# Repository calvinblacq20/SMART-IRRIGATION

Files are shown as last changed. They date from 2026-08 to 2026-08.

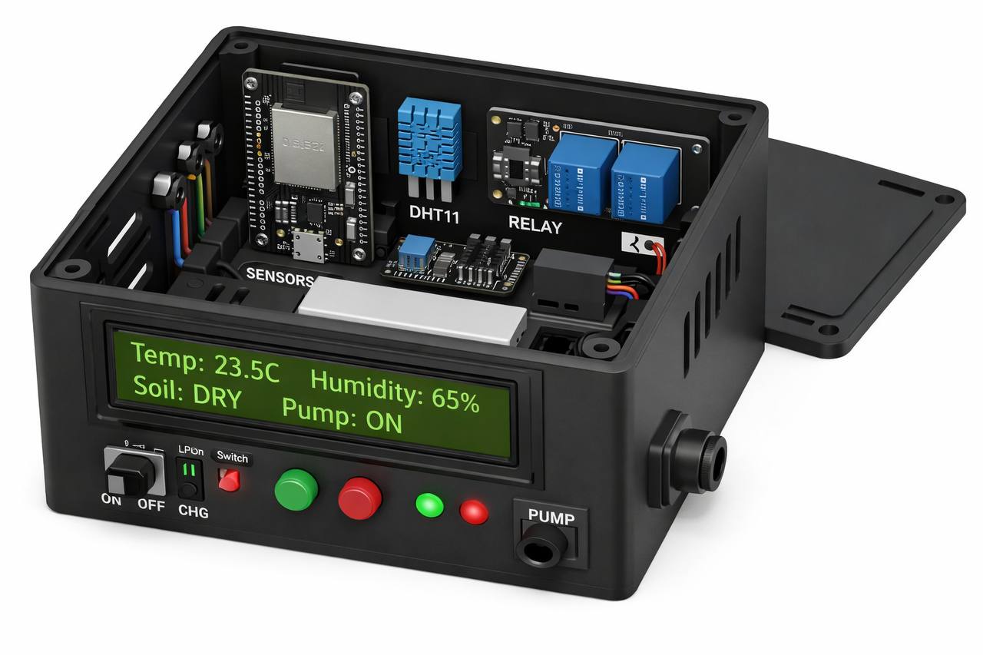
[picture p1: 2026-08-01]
photo_2_2026-06-11_17-50-46.jpg

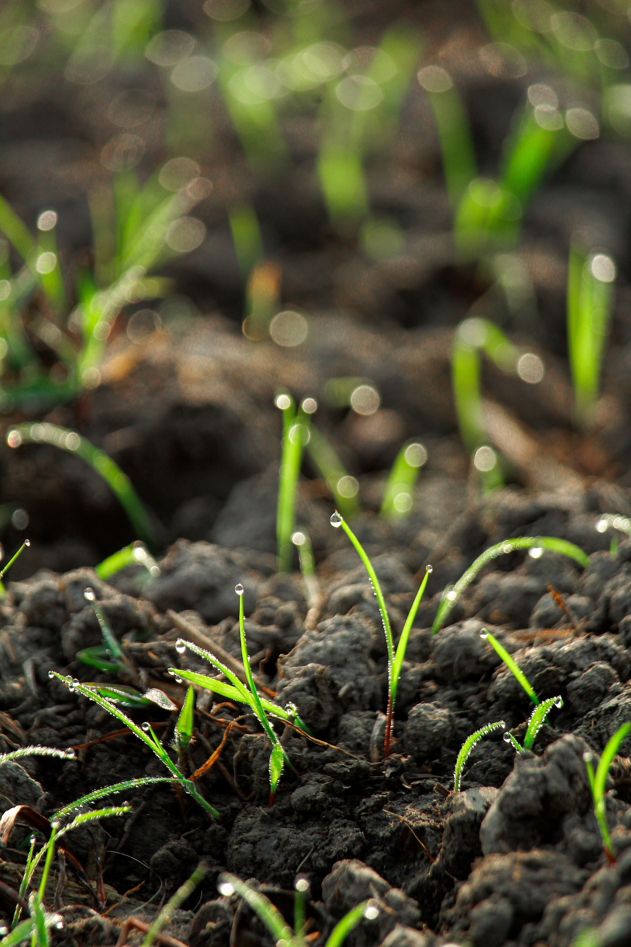
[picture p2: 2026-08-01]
webapp/bg.jpg

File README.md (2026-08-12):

# Smart Irrigation System — Project 29

An ESP8266-based automatic plant-watering controller with a REST/JSON API and a web
dashboard — servable either from the board itself or from a laptop. Reads soil moisture
and air temperature/humidity, and drives a water pump through a relay using closed-loop
control.

---

## 1. What it is (PRD summary)

**Goal.** Keep soil moisture in a healthy band automatically, with a manual override and
a clear at-a-glance status from a browser dashboard, over Wi-Fi.

**Core user action.** Watch the soil/climate readings and let the system water on its own;
optionally take manual control and tune the thresholds.

**Data shape (live state).** `soilMoisture %`, `temperature °C`, `humidity %`, `pump on/off`,
`mode auto|manual`, thresholds `startThreshold/stopThreshold`, `maxRuntimeMs`, `sensorError`.

**Control logic.** AUTO: pump ON when `soil < startThreshold`, OFF when `soil > stopThreshold`
(hysteresis). Safety: max continuous run-time (force-stop, bypasses the chatter guard) +
sensor-fault handling. MANUAL: pump follows direct API/dashboard commands.

**Out of scope.** Multi-field/multi-device fleets, cloud accounts, historical database.

---

## 2. Architecture

```
Soil sensor ──┐
              ├─► ESP8266 ──► Relay ──► Pump
DHT22 ────────┘      │
                      ├─► REST/JSON API  /api/status /api/config /api/pump /api/mode
                      │        │
                      │        ├─► dashboard served from the board itself (LittleFS,
                      │        │   gradient-mesh background) — same-origin, no laptop
                      │        │
                      │        └─► webapp/index.html (video background), served from a
                      │            laptop or Vercel, calling the API over the LAN
                      └─► mDNS  smart-irrigation.local
```

- **Firmware (active — ESP8266):** `firmware/smart_irrigation_esp8266/smart_irrigation_esp8266.ino`
  — the current connection layer: sensors, hysteresis control, REST + JSON API, mDNS. The dashboard
  is wired to this. (An earlier ESP32 build with LCD/LEDs/NVS lives in `firmware/smart_irrigation/`.)
- **Simulation:** `firmware/wokwi/` — runs the whole thing in the browser at wokwi.com.
- **Web dashboard — two builds, same UI/API, different background:**
  - `webapp/index.html` — full version with the **video background**; serve it from a laptop
    (or Vercel for a demo). Canvas soil gauge, sparklines, soil-trend chart, Home/Data/Device/
    Settings views, live + demo mode, installable (manifest + offline service worker + Install
    button).
  - `firmware/smart_irrigation_esp8266/data/index.html` — the **same dashboard**, lightweight
    (animated gradient-mesh background instead of video — the video is ~4.7 MB and won't fit on
    the board's flash). This one is **served by the ESP8266 itself** at its own IP /
    `smart-irrigation.local`, so no laptop or Vercel is needed at all — open the board's address
    on any phone/browser on the Wi-Fi and the dashboard is right there, same-origin with the API.
- **Device API:** a Wi-Fi web server on the ESP8266 exposing the JSON the dashboard reads/writes.

### Web API contract (dashboard is coded to this)
| Method/Path | Purpose |
|---|---|
| `GET /api/status` | full live state as JSON (`soilMoisture, temperature, humidity, pump, mode, sensorError, …`) |
| `GET /api/config` | thresholds: `startThreshold, stopThreshold, maxRuntimeMs` |
| `POST /api/pump` | body `{ "state": true\|false }` — manual pump (forces manual mode) |
| `POST /api/mode` | body `{ "mode": "auto"\|"manual" }` |
| `POST /api/config` | body `{ startThreshold, stopThreshold, maxRuntimeMs }` — update + clamp |

All responses send `Access-Control-Allow-Origin: *` so the standalone site can call the board.
mDNS is enabled — the board is reachable at `http://smart-irrigation.local`.

---

## 3. Repository map

| Path | What |
|---|---|
| `firmware/smart_irrigation_esp8266/` | **active firmware** — ESP8266, DHT22, REST/JSON API + mDNS |
| `firmware/smart_irrigation_esp8266/data/` | dashboard **served by the board** via LittleFS (lightweight, no video) — upload separately from the sketch, see §4 |
| `firmware/smart_irrigation/` | earlier ESP32 build (DHT11, LCD, LEDs, NVS) |
| `firmware/wokwi/` | Wokwi sim: `diagram.json`, `sketch.ino`, `libraries.txt` |
| `firmware/wiring_diagram.png` | connection diagram |
| `webapp/` | Dashboard — single-file `index.html` (**full, video background**) + `sw.js`, `manifest.json` (installable/offline). `package.json`/`vite.config.js` are just for the dev server |
| `webapp/bg.mp4`, `bg.jpg` | dashboard background video + poster |
| `*.stl` / `*.step` | 3D enclosure (body + lid), 150×120×60 mm |
| `Project29_*_Report.docx` | enclosure + firmware/software reports |

---

## 4. How to run each piece

- **Flash the board:** open `firmware/smart_irrigation_esp8266/smart_irrigation_esp8266.ino`
  in Arduino IDE, board = *NodeMCU 1.0 (ESP-12E)*, Flash Size = *4MB (FS:2MB OTA:~1019KB)*
  (the default on most boards), install **DHT sensor library** + **Adafruit Unified Sensor** +
  **ArduinoJson** + **LiquidCrystal I2C** (Frank de Brabander), fill in your Wi-Fi SSID/password,
  upload. The Serial monitor prints the IP and the dashboard URL.
  **v2.0.0 pin map:** soil → A0, DHT22 → **D7** (GPIO13 — D2 is now the I2C bus), relay → D6,
  20x4 I2C LCD (addr `0x27`) → D2 (SDA) / D1 (SCL), Manual button → D5 (to GND), Auto button →
  **D3/GPIO0** (to GND — don't hold it while powering on/resetting, it's the boot-mode pin).
  Settings persist across reboots (EEPROM).
- **Upload the on-board dashboard (LittleFS) — do this once, separately from the sketch upload:**
  install the LittleFS uploader tool — IDE 2.x: the *arduino-littlefs-upload* plugin
  ([releases](https://github.com/earlephilhower/arduino-littlefs-upload/releases), drop the
  `.vsix` in `%USERPROFILE%\.arduinoIDE\plugins\`, restart, then `Ctrl+Shift+P` →
  "Upload LittleFS to Pico/ESP8266/ESP32"; close the Serial Monitor first). IDE 1.x: the
  *ESP8266 LittleFS Data Upload* plugin. This packs `firmware/smart_irrigation_esp8266/data/`
  onto the board's flash — after that, opening the board's IP in any browser shows the dashboard
  directly, no laptop needed.
- **Simulate:** `firmware/wokwi/` — logic demonstration at wokwi.com.
- **Dashboard (video version, laptop/Vercel):** from `webapp/`, run `npm install` then
  `npm run dev -- --host` (or just serve the folder: `python -m http.server 8000`). Open it on a
  phone/laptop on the **same Wi-Fi** as the board, then Connect to `http://smart-irrigation.local`
  (or the board's IP). "Install" adds it to the home screen; the app shell then works offline.

---

## 5. Status & remaining work

1. **Firmware + dashboard** ✅ — ESP8266 REST firmware and both dashboard builds speak the same
   contract. Fill in your SSID/password, flash, (optionally) upload the LittleFS dashboard, connect.
2. **Enclosure** — the 3D enclosure still carries an LCD window / button holes from the earlier
   ESP32 build; the ESP8266 build has no on-device UI, so those provisions are now optional.
3. **Deploy** (optional) — the video-background dashboard runs from any static host (e.g. Vercel),
   but an HTTPS host cannot call an `http://` board (mixed content) — that build is demo/showcase
   only unless the dashboard is served locally or from the board itself (see §4).

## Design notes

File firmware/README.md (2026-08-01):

# Smart Irrigation System — Firmware Package

ESP32 firmware for the Smart Irrigation System (the enclosure you already 3D-modelled).
This is the **software stage** of the project. Everything you need to flash, calibrate,
and demo is here.

---

## 1. What the system does

- Reads **soil moisture**, **temperature + humidity (DHT11)**, and **light (LDR)**.
- **AUTO mode:** turns the water pump ON when soil drops below the *Dry* threshold and
  OFF when it rises above the *Wet* threshold (hysteresis, so it doesn't chatter).
- **MANUAL mode:** the pump is toggled by the MANUAL button.
- **Safety:** the pump can never run longer than *Max run* seconds, and must wait
  *Cooldown* seconds between waterings.
- **LCD 20×4** shows a live dashboard; the 3 buttons drive a settings menu.
- **LEDs:** green = healthy/idle, red = pump running or soil dry, red **blinking** = sensor fault.
- **Settings persist** in flash (survive power-off).

---

## 2. Software you need (Arduino IDE)

1. **Boards Manager** → install **“esp32” by Espressif** (adds ESP32 Dev Module).
2. **Library Manager** → install:
   - **LiquidCrystal I2C** (Frank de Brabander)
   - **DHT sensor library** (Adafruit)
   - **Adafruit Unified Sensor** (dependency of the DHT library)
   - *Preferences* and *Wire* already ship with the ESP32 core.
3. **Tools → Board:** `ESP32 Dev Module`. **Upload speed:** 921600. Select your COM port.
4. Open `smart_irrigation/smart_irrigation.ino`, click **Upload**.

Open **Serial Monitor @ 115200** to watch live readings.

---

## 3. Wiring (matches the circuit diagram)

> These are the pins the firmware uses. If any wire on your board goes to a different
> GPIO, just change that one `#define` at the top of the `.ino` — nothing else.

| Component | Signal | ESP32 pin |
|---|---|---|
| DHT11 | DATA | GPIO4 |
| Soil moisture | A0 (analog) | GPIO34 (ADC, input-only) |
| LDR module | OUT (analog) | GPIO35 (ADC, input-only) |
| LCD 20×4 (I2C) | SDA | GPIO18 |
| LCD 20×4 (I2C) | SCL | GPIO19 |
| Relay ch1 | IN1 → pump | GPIO22 |
| Relay ch2 | IN2 → spare/valve | GPIO23 |
| Button MANUAL | signal | GPIO25 |
| Button MENU | signal | GPIO26 |
| Button SETTINGS | signal | GPIO27 |
| Green LED (+220 Ω) | anode | GPIO17 |
| Red LED (+220 Ω) | anode | GPIO16 |

Power/common:
- Sensor **VCC → 3V3**, all **GND → GND** (common ground with the relay and LEDs).
- Buttons: one leg to the GPIO, the other leg to **GND** (firmware uses internal pull-ups,
  so no external resistors needed — pressed = LOW).
- **Relay board VCC → 5V (VIN)** if you have it; the coils are happier at 5V.
- **Pump is powered from the battery through the relay contacts, NOT from the ESP32.**
  Wire: Battery+ → relay **COM1**, relay **NO1** → pump+, pump− → Battery−. Add a
  flyback diode across a DC pump if the module doesn't already isolate it.

### Pins you should double-check against your own diagram
Everything works regardless, but these are the 2 worth a 5-second look:
- **I2C (LCD)** — I read your diagram’s `D18 (SDA) / D19 (SCL)` labels. If you actually
  wired the LCD to the ESP32’s default `GPIO21/GPIO22`, change `PIN_SDA`/`PIN_SCL` to `21`/`22`.
- **Relay active level** — most blue 2-channel boards are **active-LOW** (default here).
  If your pump turns on when it should be off, set `#define RELAY_ACTIVE_LOW 0`.

---

## 4. Calibrating the soil sensor (do this once)

ESP32 analog readings are 0–4095. You must tell the firmware what "dry" and "wet" look like:

1. Upload the firmware, open Serial Monitor. Each line prints `soil=..%(rawNNNN)`.
2. Hold the probe **in dry air** → note the `raw` number → put it in `SOIL_RAW_DRY`.
3. Dip the probe **in a glass of water** (up to the line) → note `raw` → put it in `SOIL_RAW_WET`.
4. Re-upload. Now `Soil:` shows ~0 % dry and ~100 % wet.

(Optional) Do the same for the LDR with `LDR_RAW_DARK` / `LDR_RAW_BRIGHT`.

---

## 5. Using the buttons

**Home screen**
- **MANUAL** — toggles the pump on/off (switches the system into MANUAL mode).
- **MENU** or **SETTINGS** — opens the settings list.

**Settings list**
- **MENU** — move to the next item.
- **SETTINGS** — edit the highlighted item (or run *Save & Exit*).
- **MANUAL** — back to Home without saving.

**Edit screen**
- **SETTINGS (+)** / **MENU (−)** — change the value.
- **MANUAL** — confirm, back to the list.

Adjustable settings: **Mode** (AUTO/MANUAL), **Dry threshold %**, **Wet threshold %**,
**Max run (s)**, **Cooldown (s)**, **Night-only** (water only when dark). Choose
*Save & Exit* to store them permanently.

---

## 6. Test / verification checklist (for your demo & report)

| # | Test | Expected result |
|---|---|---|
| 1 | Power on | LCD splash → dashboard; green LED on |
| 2 | Squeeze probe / put in water | Soil % rises; in AUTO the pump stays OFF above Wet% |
| 3 | Probe in dry air (AUTO) | Below Dry%, pump turns ON, red LED on |
| 4 | Keep pump running | After *Max run* s it auto-stops (safety) |
| 5 | Press MANUAL | Pump toggles on/off immediately |
| 6 | Unplug soil sensor | Red LED blinks (fault), pump forced OFF |
| 7 | Cover the LDR with Night-only = YES | Watering allowed only while dark |
| 8 | Change a setting → Save & Exit → reboot | New value is remembered |
| 9 | Breadboard vs enclosure | Same behaviour after transplant |

---

## 7. Troubleshooting

| Symptom | Fix |
|---|---|
| LCD blank / boxes only | Try `LCD_ADDR 0x3F`; check SDA/SCL not swapped; tweak the LCD contrast pot |
| Pump logic inverted | Set `RELAY_ACTIVE_LOW 0` |
| Soil always 0 % or 100 % | Re-run calibration (step 4); confirm A0 → GPIO34 |
| Temp/Hum show `--` | DHT11 needs VCC on 3V3, ~1 s warm-up; check DATA → GPIO4 |
| Pump won’t stop / ESP resets when pump runs | Power the pump from the battery via the relay, never from the ESP32; add flyback diode |
| WiFi later? | Move analog sensors to ADC1 pins only (GPIO32–39) — already done here |

---

## 8. Where this fits in the project

1. ✅ Circuit (line) diagram
2. ✅ 3D enclosure model  (`../body.stl`, `../lid.stl` — now correctly 150×120×60 mm)
3. ✅ Breadboard layout
4. ✅ Hand sketch
5. **➡ Firmware (this package)**
6. Assembly & wiring inside the enclosure
7. Calibration + testing (use the checklist above)
8. Final report (circuit + code + test results + photos)

Firmware file: `smart_irrigation/smart_irrigation.ino`

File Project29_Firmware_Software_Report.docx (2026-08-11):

PROJECT 29 — SMART IRRIGATION SYSTEM

Firmware / Software Report

Name | Index No. | Course | Platform
Calvin | 8985323 | Embedded Systems | ESP8266 (Arduino)

1. Software Overview

This report documents the control firmware for the Project 29 Smart Irrigation System. The firmware runs on an ESP8266 Wi-Fi module (NodeMCU) and turns the sensor and actuator hardware into a self-contained, automatic plant-watering controller with a manual override. It reads soil moisture and air temperature/humidity (DHT22), decides when the plant needs water, and switches a DC pump through a relay. Instead of an on-device LCD, the controller exposes a small REST/JSON API over Wi-Fi and advertises itself over mDNS as smart-irrigation.local; a companion installable web app (PWA) is the user interface, giving live telemetry and control from any phone or laptop on the same network.

2. Operating Principle

The controller supports two modes:

- AUTO mode uses closed-loop control with hysteresis. The pump switches ON when the soil moisture falls below the Start threshold and switches OFF once it rises above the Stop threshold. The gap between the two thresholds prevents the pump from rapidly cycling around a single set-point.
- MANUAL mode lets the operator switch the pump directly from the web app; issuing a manual pump command automatically places the controller in MANUAL mode.

Three protection rules apply: a maximum continuous run-time force-stops the pump after a set time; a 5-second chatter guard prevents relay oscillation on rapid toggles (safety shut-offs bypass this guard so they can never be swallowed); and a DHT read-failure or an apparently disconnected soil probe is flagged as a sensor fault, pausing automatic watering.

3. Hardware / Software Interface (Pin Map)

The firmware addresses each component through the ESP8266 (NodeMCU) pins below. The soil probe uses the single analog input A0; the DHT22 and relay use digital GPIOs.

Component | Signal | NodeMCU Pin | GPIO
Soil moisture sensor | AOUT (analog) | A0 | ADC0
DHT22 | DATA | D2 | GPIO4
Relay module | IN -> pump | D6 | GPIO12

The relay is active-HIGH in this build (RELAY_ON = HIGH). The relay output is initialised to OFF before the pin is set to OUTPUT, preventing a pump blip at boot. The pump is driven from its own supply through the relay contacts, never from a GPIO; fit a flyback diode across an inductive pump.

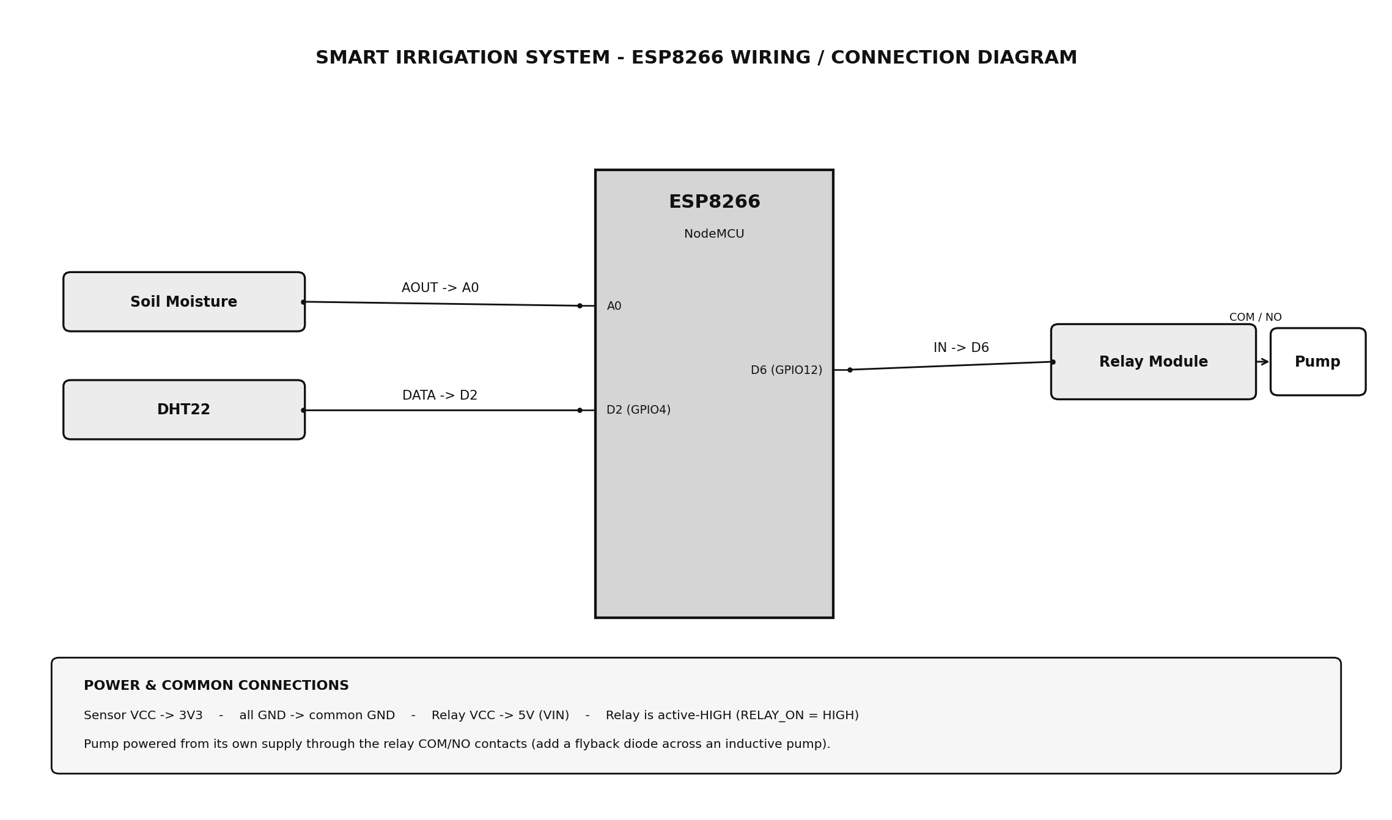
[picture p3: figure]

Figure 1 - ESP8266 wiring / connection diagram. Signal wires are labelled with the pin; power and common connections are summarised in the lower panel.

4. Program Structure & Control Flow

The program is fully non-blocking: setup() initialises the peripherals and connects to Wi-Fi, then loop() services the web server, mDNS, Wi-Fi health, the sensors, the safety timer and the control logic on their own timers without ever calling a long delay. This keeps the REST API responsive while the sensors and pump logic run in the background.

Function | Responsibility
readSensors | Timed DHT22 + soil reads; map raw ADC to 0-100 %, keep last good DHT value
updateIrrigation | AUTO hysteresis + soil-disconnect safety (skipped in MANUAL)
handlePumpSafety | Force-stop the pump once max run-time is exceeded
setPump | Drive the relay with a 5 s chatter guard (safety shut-offs force through)
handleWiFi | Non-blocking reconnect if the link drops
/api/status, /api/config | Serve live telemetry and thresholds as JSON
/api/pump, /api/mode, /api/config (POST) | Apply control + clamp settings

5. Build Environment & Libraries

Item | Selection
IDE | Arduino IDE
Board package | esp8266 by ESP8266 Community
Board | NodeMCU 1.0 (ESP-12E Module)
Upload speed | 115200 baud
Serial monitor | 115200 baud
Library | DHT sensor library (Adafruit)
Library | Adafruit Unified Sensor
Library | ArduinoJson (v6)
Built-in | ESP8266WiFi, ESP8266WebServer, ESP8266mDNS (core)

6. Soil-Sensor Calibration

Because raw ADC values depend on the specific probe and soil, the sensor is calibrated once and the two reference values are stored in the firmware constants SOIL_DRY_RAW and SOIL_WET_RAW:

- Open the Serial Monitor at 115200 baud.
- Hold the probe in dry air and record the raw value into SOIL_DRY_RAW.
- Dip the probe in a glass of water and record the raw value into SOIL_WET_RAW.
- Re-upload; the moisture reading then shows ~0 % dry and ~100 % wet.

7. REST API & Web App (User Interface)

The user interface is a Progressive Web App served separately (webapp/). It polls the controller every 3 seconds and issues control commands over the following endpoints; every response carries CORS headers so the app may be served from any local origin.

Method / Path | Purpose
GET /api/status | Live JSON: soilMoisture, temperature, humidity, pump, mode, sensorError, ip, uptime
GET /api/config | Thresholds: startThreshold, stopThreshold, maxRuntimeMs
POST /api/pump | Body {"state": true|false} - manual pump (also forces MANUAL mode)
POST /api/mode | Body {"mode": "auto"|"manual"}
POST /api/config | Body {startThreshold, stopThreshold, maxRuntimeMs} - update + clamp

On the config write the firmware clamps both thresholds to 0-100 %, clamps the run-time to 3 s - 10 min, and enforces start < stop, so an out-of-range request can never leave the controller in an unsafe state.

8. Testing & Results

The firmware was verified against the following functional tests. Record the observed result in the last column during your demonstration.

# | Test | Expected result | Pass

1 | Power on | Serial prints IP; app connects at smart-irrigation.local
2 | Probe in water (AUTO) | Soil % high; pump stays OFF above Stop %
3 | Probe in dry air (AUTO) | Below Start %, pump turns ON
4 | Hold pump running | Force-stops after Max run-time (safety)
5 | Toggle pump in app | Pump switches; controller flips to MANUAL
6 | Unplug DHT / soil probe | sensorError = true; auto watering paused
7 | POST out-of-range config | Values clamped; start < stop preserved
8 | Drop Wi-Fi, restore | Controller reconnects; app resumes polling

9. Complete Source Code Listing

File: smart_irrigation_esp8266/smart_irrigation_esp8266.ino

/*==============================================================================

SMART IRRIGATION SYSTEM — ESP8266 firmware (NodeMCU / Wemos D1)

Project 29 — updated connection layer.

REST API (dashboard is wired to this exact contract):

GET /api/status -> full live state JSON

GET /api/config -> { startThreshold, stopThreshold, maxRuntimeMs }

POST /api/pump body { "state": true|false } (forces manual mode)

POST /api/mode body { "mode": "auto"|"manual" }

POST /api/config body { startThreshold, stopThreshold, maxRuntimeMs }

OPTIONS * -> CORS pre-flight

Board: ESP8266. Sensors: soil (A0), DHT22 (D2/GPIO4). Relay: D6/GPIO12.

mDNS: http://smart-irrigation.local

Libraries (Library Manager): DHT sensor library (Adafruit), ArduinoJson (v6).

ESP8266WiFi / ESP8266WebServer / ESP8266mDNS ship with the ESP8266 core.

==============================================================================*/

#include <ESP8266WiFi.h>

#include <ESP8266WebServer.h>

#include <ESP8266mDNS.h>

#include <DHT.h>

#include <ArduinoJson.h>

#define FIRMWARE_VERSION "1.0.0"

// ==========================================

// CONFIGURATION (Adjust these before flashing)

// ==========================================

const char* WIFI_SSID = "YOUR_WIFI_NAME";

const char* WIFI_PASSWORD = "YOUR_WIFI_PASSWORD";

// Hardware Pins

const int PIN_SOIL_SENSOR = A0;

const int PIN_DHT = 4; // D2

const int PIN_RELAY = 12; // D6

// Relay logic (Change to LOW if using an Active-Low relay module)

const int RELAY_ON = HIGH;

const int RELAY_OFF = LOW;

// Soil Moisture Calibration (Raw ADC values 0-1023)

const int SOIL_DRY_RAW = 800; // Value when probe is completely dry in air

const int SOIL_WET_RAW = 300; // Value when probe is submerged in water

// DHT Setup

#define DHTTYPE DHT22

DHT dht(PIN_DHT, DHTTYPE);

// Web Server

ESP8266WebServer server(80);

// ==========================================

// SYSTEM STATE

// ==========================================

float currentTemp = 0.0;

float currentHum = 0.0;

int currentMoisture = 0; // Percentage 0-100

bool isPumpOn = false;

bool isAutoMode = true;

bool dhtError = false;

// Configurable Settings

int configStartThreshold = 35; // Start watering below 35%

int configStopThreshold = 45; // Stop watering above 45%

unsigned long configMaxPumpRuntime = 30000; // 30 seconds

// Safety clamps for /api/config

const unsigned long RUNTIME_MIN = 3000UL; // 3 s (never below the chatter window)

const unsigned long RUNTIME_MAX = 600000UL; // 10 min

// Timers & Safety

unsigned long lastDHTReadTime = 0;

unsigned long lastSoilReadTime = 0;

unsigned long lastWiFiCheckTime = 0;

unsigned long pumpStartTime = 0;

unsigned long lastRelaySwitchTime = 0;

const unsigned long DHT_INTERVAL = 2500; // 2.5 seconds

const unsigned long SOIL_INTERVAL = 1000; // 1 second

const unsigned long WIFI_INTERVAL = 10000; // 10 seconds

const unsigned long MIN_RELAY_DELAY = 5000;// Minimum 5 seconds between relay toggles (Chatter protection)

// ==========================================

// SETUP

// ==========================================

void setup() {

Serial.begin(115200);

delay(100);

Serial.println(F("\n===================================="));

Serial.println(F("SMART IRRIGATION SYSTEM"));

Serial.print(F("Firmware: "));

Serial.println(FIRMWARE_VERSION);

Serial.print(F("Reset Reason: "));

Serial.println(ESP.getResetReason());

Serial.println(F("===================================="));

initializePins();

initializeSensors();

initializeWiFi();

initializeWebServer();

initializeMDNS();

Serial.println(F("System ready."));

}

// ==========================================

// LOOP

// ==========================================

void loop() {

server.handleClient();

MDNS.update();

handleWiFi();

readSensors();

handlePumpSafety();

updateIrrigation();

}

// ==========================================

// INITIALIZATION FUNCTIONS

// ==========================================

void initializePins() {

// IMPORTANT: Set default state BEFORE making it an output to prevent relay blips on boot

digitalWrite(PIN_RELAY, RELAY_OFF);

pinMode(PIN_RELAY, OUTPUT);

Serial.println(F("Pins initialized. Pump is OFF."));

}

void initializeSensors() {

dht.begin();

Serial.println(F("Sensors initialized."));

}

void initializeWiFi() {

Serial.print(F("Connecting to WiFi: "));

Serial.println(WIFI_SSID);

WiFi.mode(WIFI_STA);

WiFi.begin(WIFI_SSID, WIFI_PASSWORD);

// Non-blocking wait, give it 10 seconds maximum during boot

unsigned long startAttemptTime = millis();

while (WiFi.status() != WL_CONNECTED && millis() - startAttemptTime < 10000) {

delay(500);

Serial.print(F("."));

}

if (WiFi.status() == WL_CONNECTED) {

Serial.println(F("\nWiFi connected."));

Serial.print(F("IP address: "));

Serial.println(WiFi.localIP());

} else {

Serial.println(F("\nWiFi connection timed out. Proceeding offline."));

}

}

void initializeMDNS() {

if (MDNS.begin("smart-irrigation")) {

MDNS.addService("http", "tcp", 80);

Serial.println(F("mDNS responder started at smart-irrigation.local"));

}

}

// ==========================================

// CORE LOGIC FUNCTIONS

// ==========================================

void handleWiFi() {

if (millis() - lastWiFiCheckTime >= WIFI_INTERVAL) {

lastWiFiCheckTime = millis();

if (WiFi.status() != WL_CONNECTED) {

Serial.println(F("WiFi disconnected. Attempting reconnect (non-blocking)..."));

WiFi.disconnect();

WiFi.begin(WIFI_SSID, WIFI_PASSWORD);

}

}

}

void readSensors() {

unsigned long currentMillis = millis();

// Read DHT22

if (currentMillis - lastDHTReadTime >= DHT_INTERVAL) {

lastDHTReadTime = currentMillis;

float t = dht.readTemperature();

float h = dht.readHumidity();

if (isnan(t) || isnan(h)) {

if (!dhtError) {

Serial.println(F("Warning: DHT sensor read failure."));

dhtError = true;

}

} else {

currentTemp = t;

currentHum = h;

dhtError = false;

}

}

// Read Soil Moisture

if (currentMillis - lastSoilReadTime >= SOIL_INTERVAL) {

lastSoilReadTime = currentMillis;

int rawValue = analogRead(PIN_SOIL_SENSOR);

// Map raw ADC to percentage, constrain to 0-100

currentMoisture = map(rawValue, SOIL_DRY_RAW, SOIL_WET_RAW, 0, 100);

currentMoisture = constrain(currentMoisture, 0, 100);

}

}

// force=true bypasses chatter protection — used ONLY by safety shut-offs so a

// max-runtime or sensor-fault cutoff can never be swallowed by the 5 s guard.

void setPump(bool state, String reason, bool force = false) {

if (!force && millis() - lastRelaySwitchTime < MIN_RELAY_DELAY) {

return; // Ignore normal command if trying to switch too fast

}

if (state && !isPumpOn) {

digitalWrite(PIN_RELAY, RELAY_ON);

isPumpOn = true;

pumpStartTime = millis();

lastRelaySwitchTime = millis();

Serial.print(F("Pump ON - Reason: "));

Serial.println(reason);

}

else if (!state && isPumpOn) {

digitalWrite(PIN_RELAY, RELAY_OFF);

isPumpOn = false;

lastRelaySwitchTime = millis();

Serial.print(F("Pump OFF - Reason: "));

Serial.println(reason);

}

}

void updateIrrigation() {

if (!isAutoMode) return;

// Sanity check: If moisture sensor disconnected/broken, do not water

if (currentMoisture <= 0 && analogRead(PIN_SOIL_SENSOR) > 1000 && SOIL_DRY_RAW < 1000) {

if (isPumpOn) setPump(false, "Safety: Soil sensor appears disconnected", true);

return;

}

// Hysteresis logic

if (currentMoisture < configStartThreshold && !isPumpOn) {

setPump(true, "Auto Start (Moisture Low)");

}

else if (currentMoisture > configStopThreshold && isPumpOn) {

setPump(false, "Auto Stop (Moisture High)");

}

}

void handlePumpSafety() {

if (isPumpOn) {

if (millis() - pumpStartTime >= configMaxPumpRuntime) {

setPump(false, "Safety: Max Runtime Exceeded", true); // force: must never be blocked

}

}

}

// ==========================================

// HTTP SERVER / API HANDLERS

// ==========================================

void sendCORSHeaders() {

server.sendHeader(F("Access-Control-Allow-Origin"), F("*"));

server.sendHeader(F("Access-Control-Allow-Methods"), F("GET, POST, OPTIONS"));

server.sendHeader(F("Access-Control-Allow-Headers"), F("Content-Type"));

}

void handleOptions() {

sendCORSHeaders();

server.send(204); // No Content

}

void initializeWebServer() {

// Pre-flight CORS request

server.onNotFound([]() {

if (server.method() == HTTP_OPTIONS) {

handleOptions();

} else {

sendCORSHeaders();

server.send(404, "application/json", "{\"success\":false,\"error\":\"Not Found\"}");

}

});

server.on("/api/status", HTTP_GET, []() {

StaticJsonDocument<384> doc;

doc["device"] = "smart-irrigation";

doc["version"] = FIRMWARE_VERSION;

doc["ip"] = WiFi.localIP().toString();

doc["uptime"] = millis() / 1000;

doc["wifi"] = (WiFi.status() == WL_CONNECTED);

doc["mode"] = isAutoMode ? "auto" : "manual";

doc["pump"] = isPumpOn;

doc["soilMoisture"] = currentMoisture;

doc["temperature"] = currentTemp;

doc["humidity"] = currentHum;

doc["sensorError"] = dhtError;

String response;

serializeJson(doc, response);

sendCORSHeaders();

server.send(200, "application/json", response);

});

server.on("/api/config", HTTP_GET, []() {

StaticJsonDocument<200> doc;

doc["startThreshold"] = configStartThreshold;

doc["stopThreshold"] = configStopThreshold;

doc["maxRuntimeMs"] = configMaxPumpRuntime;

String response;

serializeJson(doc, response);

sendCORSHeaders();

server.send(200, "application/json", response);

});

server.on("/api/pump", HTTP_POST, []() {

sendCORSHeaders();

if (server.hasArg("plain") == false) {

server.send(400, "application/json", "{\"success\":false,\"error\":\"Body required\"}");

return;

}

StaticJsonDocument<200> doc;

DeserializationError error = deserializeJson(doc, server.arg("plain"));

if (error) {

server.send(400, "application/json", "{\"success\":false,\"error\":\"Invalid JSON\"}");

return;

}

if (!doc.containsKey("state")) {

server.send(400, "application/json", "{\"success\":false,\"error\":\"Missing 'state' boolean\"}");

return;

}

bool requestedState = doc["state"];

// Switch to manual mode if controlling pump via API

isAutoMode = false;

setPump(requestedState, "API Manual Request");

// Report the ACTUAL pump state (chatter protection may have deferred the switch)

String resp = String("{\"success\":true,\"pump\":") + (isPumpOn ? "true" : "false") + "}";

server.send(200, "application/json", resp);

});

server.on("/api/mode", HTTP_POST, []() {

sendCORSHeaders();

if (server.hasArg("plain") == false) {

server.send(400, "application/json", "{\"success\":false,\"error\":\"Body required\"}");

return;

}

StaticJsonDocument<200> doc;

DeserializationError error = deserializeJson(doc, server.arg("plain"));

if (error) {

server.send(400, "application/json", "{\"success\":false,\"error\":\"Invalid JSON\"}");

return;

}

String mode = doc["mode"];

if (mode == "auto") {

isAutoMode = true;

} else if (mode == "manual") {

isAutoMode = false;

} else {

server.send(400, "application/json", "{\"success\":false,\"error\":\"Invalid mode\"}");

return;

}

server.send(200, "application/json", "{\"success\":true}");

});

server.on("/api/config", HTTP_POST, []() {

sendCORSHeaders();

if (server.hasArg("plain") == false) {

server.send(400, "application/json", "{\"success\":false,\"error\":\"Body required\"}");

return;

}

StaticJsonDocument<200> doc;

DeserializationError error = deserializeJson(doc, server.arg("plain"));

if (error) {

server.send(400, "application/json", "{\"success\":false,\"error\":\"Invalid JSON\"}");

return;

}

if (doc.containsKey("startThreshold")) configStartThreshold = doc["startThreshold"];

if (doc.containsKey("stopThreshold")) configStopThreshold = doc["stopThreshold"];

if (doc.containsKey("maxRuntimeMs")) configMaxPumpRuntime = doc["maxRuntimeMs"].as<unsigned long>();

// Validate boundaries (clamp to sane ranges, then enforce hysteresis gap)

configStartThreshold = constrain(configStartThreshold, 0, 100);

configStopThreshold = constrain(configStopThreshold, 0, 100);

if (configMaxPumpRuntime < RUNTIME_MIN) configMaxPumpRuntime = RUNTIME_MIN;

if (configMaxPumpRuntime > RUNTIME_MAX) configMaxPumpRuntime = RUNTIME_MAX;

if (configStartThreshold >= configStopThreshold) {

configStartThreshold = configStopThreshold - 5; // Enforce minimum hysteresis

if (configStartThreshold < 0) configStartThreshold = 0;

}

server.send(200, "application/json", "{\"success\":true}");

});

server.begin();

}

10. Conclusion

The firmware implements the full Project 29 control scheme: automatic hysteresis-based irrigation with manual override, a REST/JSON API with an installable web app for configuration and monitoring, safety limits (max run-time, chatter guard, sensor-fault handling) and input clamping. It compiles for the NodeMCU (ESP8266) using the standard Arduino toolchain and maps directly to the components in the circuit diagram, completing the software stage of the project.

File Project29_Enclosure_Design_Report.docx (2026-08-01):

PROJECT 29 — SMART IRRIGATION SYSTEM

Enclosure Design Report

Name | Index No. | Course | Date
Calvin | 8985323 | Embedded Systems | 11 June 2026

1. Design Overview

The enclosure is a benchtop instrument case that houses the complete Smart Irrigation controller. The display and all user controls sit on the front panel for easy reading and operation, while the ESP32, DHT11 and relay module mount on internal standoffs above a dedicated battery bay. A removable lid gives full access for assembly and debugging. This layout was chosen over a sealed weatherproof box because the unit is operated and graded on a desk, and every component must remain visible and serviceable.

2. Overall Dimensions

All dimensions are stated in centimetres (cm), as required.

Parameter | Value (cm)
Overall width | 15.0
Overall depth | 12.0
Overall height | 6.0
Wall thickness | 0.3
Corner radius | 0.6
Lid clearance | 0.04

3. Dimensioned Drawing

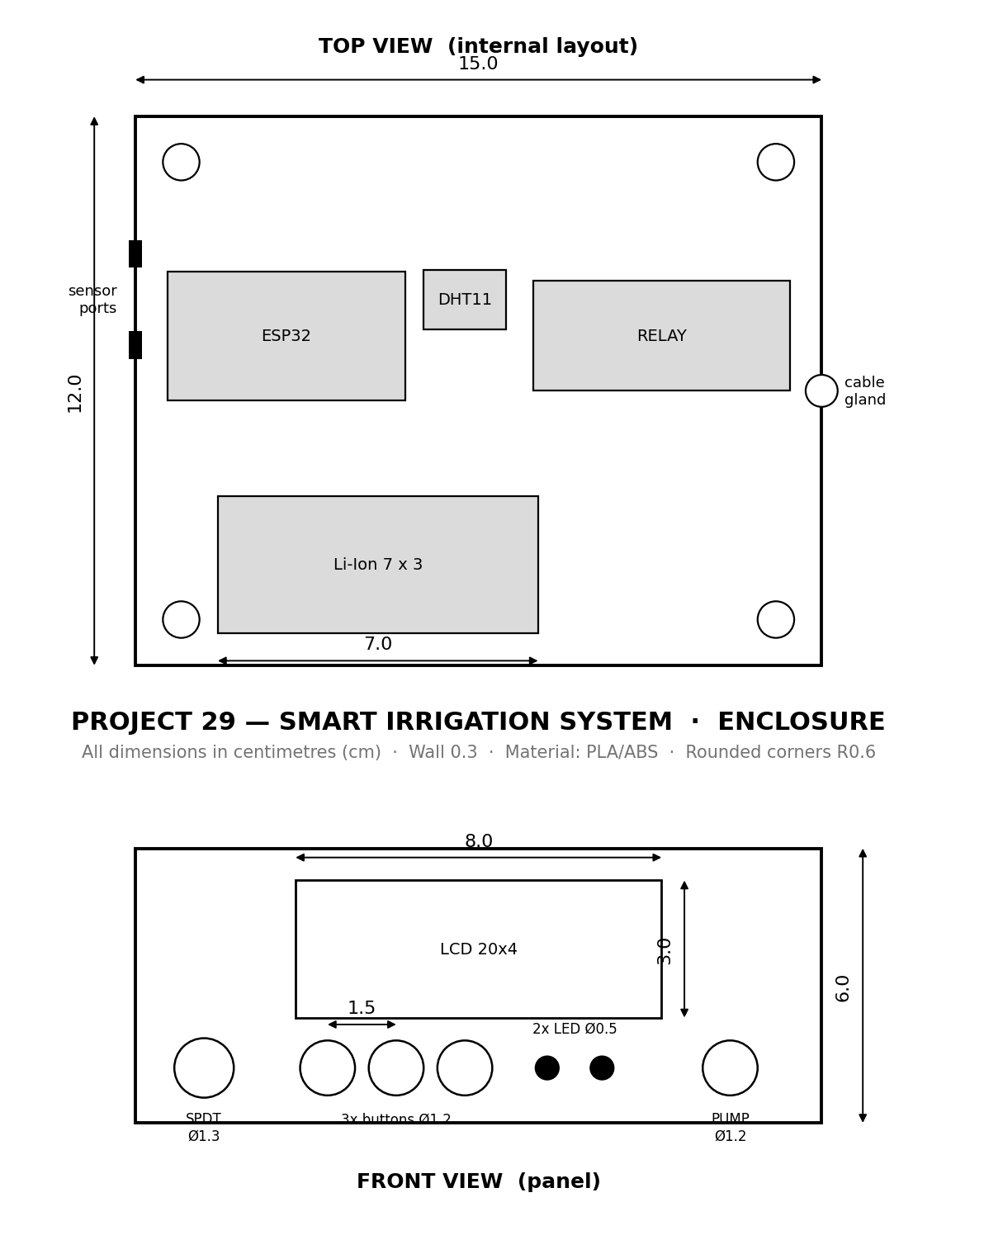
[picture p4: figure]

Figure 1 — Top view (internal layout) and front view (panel). Dimensions in cm.

4. Front Panel Layout

Feature | Size (cm) | Qty
LCD 20x4 window | 8.0 x 3.0 | 1
Tactile buttons | Ø1.2 (1.5 spacing) | 3
Indicator LEDs | Ø0.5 | 2
SPDT power switch | Ø1.3 | 1
Pump output jack | Ø1.2 | 1

5. Internal Layout & Component Mounting

Every component from the Project 29 brief maps to a physical feature of the enclosure:

Component | Mounting / feature
ESP32 dev module | 4 standoffs, left bay
DHT11 sensor | 2 standoffs, centre
LDR module | left-side sensor port
Soil-sensor wiring | left-side sensor ports
Relay module (2-ch) | 4 standoffs, right bay
LCD 20x4 + I2C | 8 x 3 cm front window
Tactile buttons | 3 x Ø1.2 cm holes @ 1.5 cm
Indicator LEDs | 2 x Ø0.5 cm holes
SPDT switch | Ø1.3 cm hole
Li-Ion battery + case | 7 x 3 cm battery bay
Water pump output | Ø1.2 cm jack + cable gland

6. Ports, Access & Ventilation

Location | Feature
Left side | 3 sensor-port slots (soil probe + LDR wiring)
Right side | Cable gland Ø1.2 cm + 4 ventilation slots
Top | Removable lid, 4 corner screws (self-locating lip)

7. Materials & Manufacturing

The enclosure is designed for FDM 3D printing in PLA or ABS with 0.3 cm walls. The body prints open-side-up with no supports; the lid prints flat. The four corner bosses accept M2.5 self-tapping screws to secure the lid. Rounded R0.6 cm corners improve strength and finish.

8. Rendered Assembly

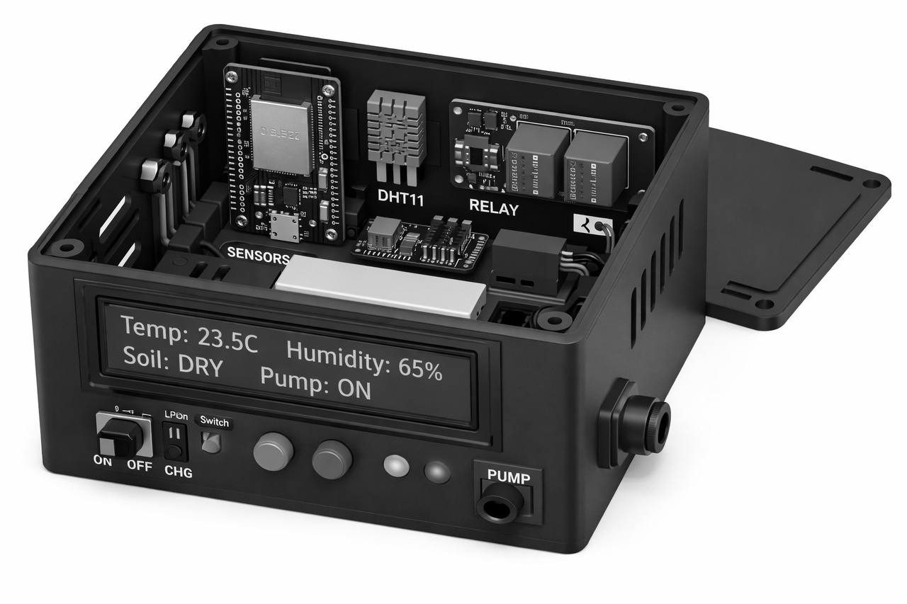
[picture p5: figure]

Figure 2 — Assembled concept render (grayscale) showing the populated panel.

9. CAD Files Delivered

File | Purpose
irrigation_body_cm.step | Import into OnShape (centimetre units)
irrigation_lid_cm.step | Lid — import into OnShape
irrigation_body_mm.step / lid | Millimetre backup for other CAD tools
irrigation_body.stl / lid | 3D printing (slicer)
build_final_cm.py | Editable parametric source (all cm parameters)

10. Model Generation & Verification

The geometry was produced from a parametric CadQuery (Python) script in which every dimension is a named centimetre parameter. The STEP files were verified by re-importing and measuring the bounding box: the centimetre file imports at exactly 15.0 x 12.0 x 6.0 cm, confirming the unit and scale are correct before any CAD or print work.

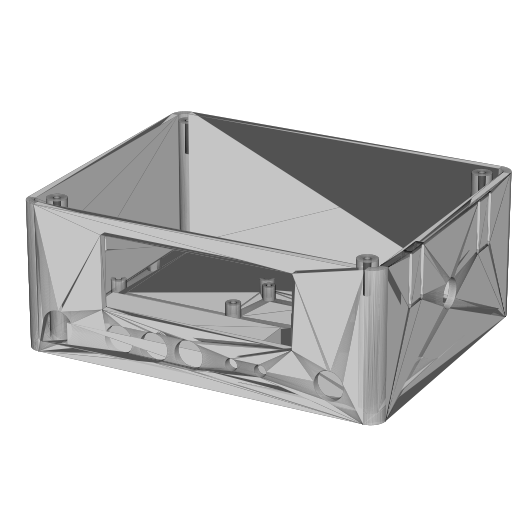
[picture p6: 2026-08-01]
preview_front_iso.png

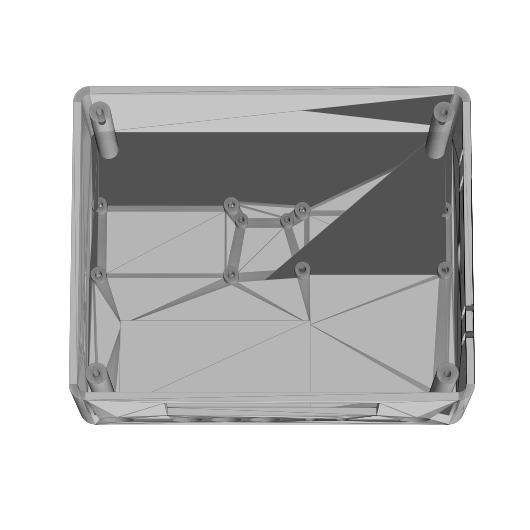
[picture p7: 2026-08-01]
preview_top.png

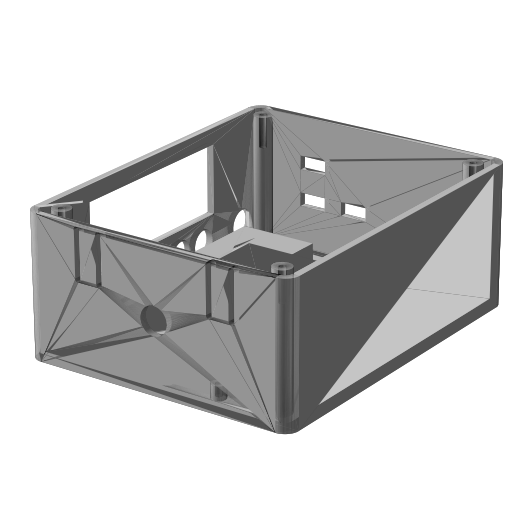
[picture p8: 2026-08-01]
preview_right_iso.png

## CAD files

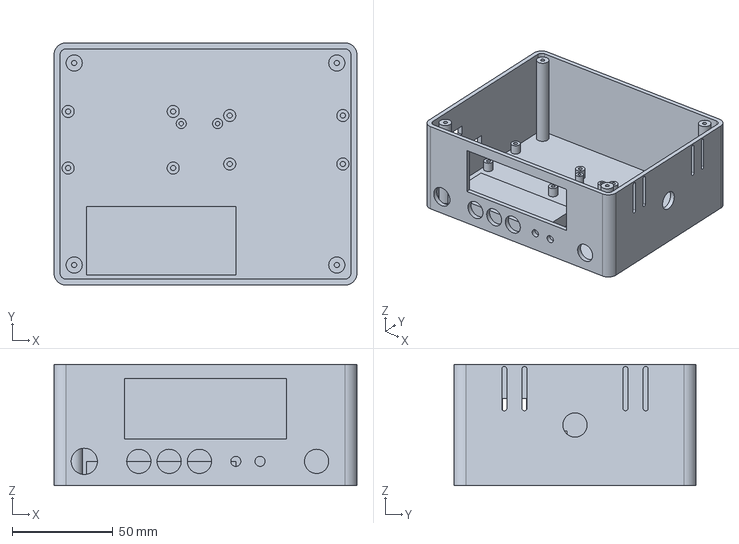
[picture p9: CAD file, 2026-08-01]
irrigation_body_cm.step
150.0 x 120.0 x 60.0 mm

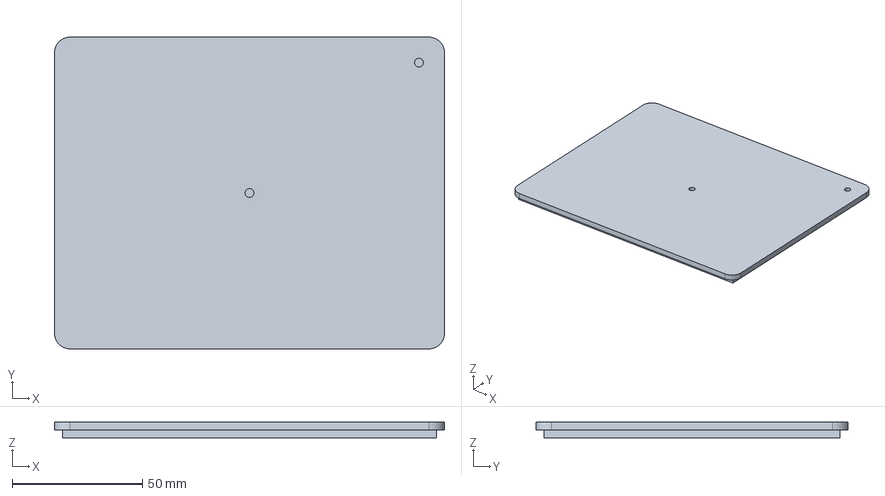
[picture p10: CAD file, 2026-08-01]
irrigation_lid_cm.step
149.6 x 119.6 x 6.00 mm

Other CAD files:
body.stl
irrigation_lid_mm.step
irrigation_lid.stl
irrigation_body.stl
irrigation_body_mm.step
lid.stl

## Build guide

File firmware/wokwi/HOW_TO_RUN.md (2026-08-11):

# Run the Smart Irrigation System live in Wokwi (free, in your browser)

> **Note on the board.** The shipped/graded firmware is the ESP8266 REST build
> (`../smart_irrigation_esp8266/`). Wokwi does **not** provide an ESP8266/NodeMCU board,
> so this folder is a **control-logic demonstration on an ESP32** — the same hysteresis,
> pump and safety behaviour, visualised with an LCD + LEDs you don't need on the real board.
> Use it to show the logic working; use the ESP8266 sketch + the PWA for the real system.

Wokwi is a free online simulator — no install, no login needed to run.
You "open" this project the same way you imported the STL into Onshape:
create a blank ESP32 project, then paste in these two files.

## Files in this folder
| File | What it is |
|---|---|
| `diagram.json` | the wiring (ESP32 + all components) |
| `sketch.ino` | the firmware (simulation build) |
| `libraries.txt` | libraries Wokwi installs automatically |

## Steps (2 minutes)
1. Go to **https://wokwi.com/projects/new/esp32**
2. Click the **`diagram.json`** tab → select all → paste the contents of `diagram.json`.
3. Click the **`sketch.ino`** tab → select all → paste the contents of `sketch.ino`.
4. Add the libraries: click the **Library Manager** (📚 icon on the left) → search and add
   **DHT sensor library**, **Adafruit Unified Sensor**, **LiquidCrystal I2C**.
   *(Or: click the `+` next to the file tabs → New File → name it `libraries.txt` → paste
   the contents of `libraries.txt`. Wokwi then installs them for you.)*
5. Press the green **▶ Play** button. The LCD lights up and shows the dashboard.

## What you'll see / how to drive the demo
- **Soil moisture** = the **potentiometer** on the left. Turn it **down (dry)** → in AUTO
  mode the **relay clicks ON** (pump) and the **red LED** lights. Turn it **up (wet)** past
  the Wet threshold → pump turns **OFF**, **green LED** on.
- **DHT22** = drag its temperature/humidity sliders; values appear on the LCD.
- **Light** = the photoresistor's light slider (used only if you enable *Night-only*).
- **Buttons**: **MANUAL** toggles the pump by hand; **MENU** opens settings, **SET** edits /
  saves (see the button map in the main README).
- The **relay module** clicks and its LED lights when the pump is "running".
- Open the **Serial Monitor** (bottom panel) to watch live readings @ 115200.

## Notes
- This is the **same firmware** as `../smart_irrigation/smart_irrigation.ino`, with only
  3 simulation tweaks (marked at the top of `sketch.ino`): DHT22 instead of DHT11, the
  soil/light calibration set for the sim sliders, and shorter pump timers so it cycles fast.
- On the **real board** use the original `smart_irrigation.ino` (DHT11, your calibrated values).
- Pins in the sim match the firmware: I2C on GPIO18/19, relay on GPIO22, etc.

## Optional: even faster to open
If you use VS Code, install the **Wokwi for VS Code** extension, drop `diagram.json`,
`sketch.ino` and a compiled binary in a folder with a `wokwi.toml`, and press F1 →
"Wokwi: Start Simulator". For a quick look, the website steps above are easiest.

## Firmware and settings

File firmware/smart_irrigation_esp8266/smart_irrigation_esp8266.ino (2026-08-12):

/**
 * =================================================================================
 * SMART IRRIGATION SYSTEM - PRODUCTION ESP8266 FIRMWARE (v2.0.0)
 * Architectural Blueprint: Embedded Systems Standard (Non-Blocking, Failsafe)
 * Project 29
 * =================================================================================
 * Features:
 *  - Non-volatile configuration persistence via EEPROM
 *  - Non-blocking cooperative multitasking scheduler
 *  - Moving-average digital filter for analog soil sensor readings
 *  - Hardware chatter protection with instant REST manual overrides
 *  - Differential 20x4 LCD buffer rendering engine (zero flicker)
 *  - Failsafe watchdog timer & emergency runtime cutoff
 *  - High-performance REST API with full CORS support
 *
 * REST API (dashboard is wired to this exact contract):
 *   GET  /api/status  -> full live state JSON
 *   GET  /api/config  -> { startThreshold, stopThreshold, maxRuntimeMs }
 *   POST /api/pump    body { "state": true|false }   (forces manual mode)
 *   POST /api/mode    body { "mode": "auto"|"manual" }
 *   POST /api/config  body { startThreshold, stopThreshold, maxRuntimeMs }
 *   OPTIONS *         -> CORS pre-flight
 *
 * === DASHBOARD IS SERVED FROM THE BOARD ITSELF ===
 * The data/ folder next to this .ino holds a lightweight build of the
 * dashboard (index.html, manifest.json, sw.js — no video background, it's
 * too large for on-board flash). Upload it to LittleFS SEPARATELY from the
 * sketch, using the Arduino IDE's LittleFS uploader tool:
 *   - IDE 2.x (2.2.1+): "arduino-littlefs-upload" plugin
 *       github.com/earlephilhower/arduino-littlefs-upload — download the
 *       .vsix from its Releases page, place it in
 *       <home>\.arduinoIDE\plugins\ (Windows) and restart the IDE, then
 *       Ctrl+Shift+P -> "Upload LittleFS to Pico/ESP8266/ESP32"
 *       (close the Serial Monitor first or the upload will fail)
 *   - IDE 1.x: "ESP8266 LittleFS Data Upload" plugin
 *       github.com/earlephilhower/arduino-esp8266littlefs-plugin
 * Board setting: Tools -> Flash Size -> "4MB (FS:2MB OTA:~1019KB)" (default
 * on most NodeMCU boards) — the dashboard is ~60 KB, comfortably inside 2 MB.
 * If LittleFS isn't uploaded (or fails to mount), the API still works fine —
 * only the on-board dashboard route is skipped; use webapp/index.html
 * (laptop-served, full video background) instead.
 *
 * Libraries (Library Manager): DHT sensor library (Adafruit), Adafruit
 * Unified Sensor, ArduinoJson (v6), LiquidCrystal I2C (Frank de Brabander).
 * ESP8266WiFi / ESP8266WebServer / ESP8266mDNS / LittleFS / EEPROM / Wire
 * ship with the ESP8266 core.
 * =================================================================================
 */

#include <ArduinoJson.h>
#include <DHT.h>
#include <EEPROM.h>
#include <ESP8266WebServer.h>
#include <ESP8266WiFi.h>
#include <ESP8266mDNS.h>
#include <LiquidCrystal_I2C.h>
#include <LittleFS.h>
#include <Wire.h>

#define FIRMWARE_VERSION "2.0.0"
#define EEPROM_MAGIC_KEY 0x49525249 // 'IRRI' magic byte for config validation

// =================================================================================
// 1. HARDWARE PIN DEFINITIONS & CONSTANTS
// =================================================================================
// NOTE: DHT moved off D2/GPIO4 because D2 is now the I2C bus (LCD) —
// Wire.begin() defaults to SDA=D2(GPIO4), SCL=D1(GPIO5) on the NodeMCU.
namespace HardwarePin {
constexpr uint8_t SOIL_SENSOR = A0;
constexpr uint8_t DHT_DATA = 13;   // ESP8266 D7
constexpr uint8_t RELAY = 12;      // ESP8266 D6
constexpr uint8_t BTN_MANUAL = 14; // ESP8266 D5
constexpr uint8_t BTN_AUTO = 0;    // ESP8266 D3 (also the boot-mode pin —
                                    // don't hold this button while powering
                                    // on / resetting the board)
} // namespace HardwarePin

namespace RelayLogic {
constexpr uint8_t ACTIVE = HIGH; // Active HIGH relay configuration
constexpr uint8_t INACTIVE = LOW;
} // namespace RelayLogic

namespace SoilCalibration {
constexpr int RAW_DRY = 800;          // Sensor value in dry air
constexpr int RAW_WET = 300;          // Sensor value fully submerged
constexpr uint8_t FILTER_SAMPLES = 8; // Moving average sample size
} // namespace SoilCalibration

// Safety clamps applied to values written via POST /api/config
namespace ConfigLimits {
constexpr int THRESHOLD_MIN = 0;
constexpr int THRESHOLD_MAX = 100;
constexpr uint32_t RUNTIME_MIN_MS = 3000UL;   // 3 s
constexpr uint32_t RUNTIME_MAX_MS = 600000UL; // 10 min
} // namespace ConfigLimits

// DHT Sensor Configuration — this build's sensor is a DHT22 (per the wired
// hardware/circuit diagram). Change to DHT11 only if you swap the physical
// sensor module.
#define DHTTYPE DHT22
DHT dht(HardwarePin::DHT_DATA, DHTTYPE);

// 20x4 LCD Setup
LiquidCrystal_I2C lcd(0x27, 20, 4);

// Web Server
ESP8266WebServer server(80);

// =================================================================================
// 2. DOMAIN ENUMS & CONFIGURATION STRUCTURES
// =================================================================================
enum class SystemMode : uint8_t { AUTO = 0, MANUAL = 1 };

enum class PumpState : uint8_t { OFF = 0, ON = 1 };

struct EEPROMConfig {
  uint32_t magic;
  int startThreshold;    // Moisture % to start auto-irrigation
  int stopThreshold;     // Moisture % to stop auto-irrigation
  uint32_t maxRuntimeMs; // Maximum continuous pump runtime limit
};

// Global System Configuration
EEPROMConfig config = {
    EEPROM_MAGIC_KEY,
    35,   // default start threshold: 35%
    45,   // default stop threshold: 45%
    30000 // default max runtime: 30000ms (30 seconds)
};

// =================================================================================
// 3. SYSTEM STATE MACHINE & TELEMETRY
// =================================================================================
struct SystemTelemetry {
  float temperature = 0.0f;
  float humidity = 0.0f;
  int soilMoisture = 0;
  int rawSoilAnalog = 0;

  SystemMode mode = SystemMode::AUTO;
  PumpState pump = PumpState::OFF;

  bool dhtSensorError = false;
  bool soilSensorError = false;

  uint32_t pumpStartTime = 0;
  uint32_t lastRelayToggleTime = 0;
  uint32_t lastSensorReadTime = 0;
  uint32_t lastLCDRefreshTime = 0;
  uint32_t lastWiFiCheckTime = 0;
} sysState;

// Button Debounce Objects
struct ButtonDebouncer {
  uint8_t pin;
  bool currentState;
  bool lastState;
  uint32_t lastDebounceTime;
};

ButtonDebouncer btnManual = {HardwarePin::BTN_MANUAL, HIGH, HIGH, 0};
ButtonDebouncer btnAuto = {HardwarePin::BTN_AUTO, HIGH, HIGH, 0};

constexpr uint32_t DEBOUNCE_DELAY_MS = 40;
constexpr uint32_t MIN_AUTO_CHATTER_DELAY_MS =
    1500; // Chatter protection for Auto Mode

// Whether the on-board dashboard filesystem mounted successfully.
// API routes work either way — this only gates the static file routes.
bool filesystemOk = false;

// =================================================================================
// Wi-Fi credentials — fill these in before flashing.
// NEVER commit real credentials to a public repo.
// =================================================================================
const char *WIFI_SSID = "YOUR_WIFI_NAME";
const char *WIFI_PASSWORD = "YOUR_WIFI_PASSWORD";

// =================================================================================
// 4. FUNCTION DECLARATIONS
// =================================================================================
void loadEEPROMConfig();
void saveEEPROMConfig();

void initHardware();
void initFilesystem();
void initWiFi();
void initWebServer();

void taskServiceNetwork();
void taskReadSensors();
void taskHandleButtons();
void taskIrrigationControl();
void taskUpdateDisplay();

bool executePumpState(PumpState newState, const char *reason,
                      bool bypassLockout = false);
void setSystemMode(SystemMode newMode, const char *reason);
int readFilteredSoilMoisture();
void sendCORSHeaders();

// =================================================================================
// 5. SETUP & MAIN LOOP (NON-BLOCKING SCHEDULER)
// =================================================================================
void setup() {
  Serial.begin(115200);
  delay(100);

  Serial.println(F("\n=============================================="));
  Serial.println(F(" SMART IRRIGATION SYSTEM - ESP8266 FIRMWARE  "));
  Serial.println(F(" Architecture: Non-Blocking Event Loop v2.0  "));
  Serial.println(F("=============================================="));

  EEPROM.begin(sizeof(EEPROMConfig));
  loadEEPROMConfig();

  initHardware();
  initFilesystem();
  initWiFi();
  initWebServer();

  if (MDNS.begin("smart-irrigation")) {
    MDNS.addService("http", "tcp", 80);
    Serial.println(
        F("[mDNS] Domain registered: http://smart-irrigation.local"));
  }

  Serial.println(
      F("[System] Initialization complete. Entering main task scheduler.\n"));
}

void loop() {
  // Feed ESP8266 Software Watchdog Timer
  ESP.wdtFeed();

  // Task 1: Network & HTTP Requests Service
  taskServiceNetwork();

  // Task 2: Digital & Analog Sensor Acquisition (Periodic)
  taskReadSensors();

  // Task 3: Physical Pushbutton Debouncing & ISR Handling
  taskHandleButtons();

  // Task 4: Irrigation Logic Engine & Emergency Safety Timers
  taskIrrigationControl();

  // Task 5: LCD 20x4 Screen Differential Renderer
  taskUpdateDisplay();
}

// =================================================================================
// 6. EEPROM STORAGE ENGINE
// =================================================================================
void loadEEPROMConfig() {
  EEPROMConfig stored;
  EEPROM.get(0, stored);

  if (stored.magic == EEPROM_MAGIC_KEY) {
    config = stored;
    Serial.println(F("[EEPROM] Valid configuration loaded successfully."));
  } else {
    Serial.println(F("[EEPROM] Magic key mismatch. Writing default settings."));
    saveEEPROMConfig();
  }
}

void saveEEPROMConfig() {
  config.magic = EEPROM_MAGIC_KEY;
  EEPROM.put(0, config);
  EEPROM.commit();
  Serial.println(F("[EEPROM] Configuration saved to flash storage."));
}

// =================================================================================
// 7. HARDWARE & PERIPHERAL INITIALIZATION
// =================================================================================
void initHardware() {
  // Relay Pin Configuration (Set inactive before output mode to prevent relay
  // power click)
  digitalWrite(HardwarePin::RELAY, RelayLogic::INACTIVE);
  pinMode(HardwarePin::RELAY, OUTPUT);

  // Button Inputs with Pull-Up
  pinMode(HardwarePin::BTN_MANUAL, INPUT_PULLUP);
  pinMode(HardwarePin::BTN_AUTO, INPUT_PULLUP);

  // Sensor Subsystem
  dht.begin();

  // 20x4 I2C LCD Display Initialization
  Wire.begin();
  lcd.init();
  lcd.backlight();
  lcd.clear();
  lcd.setCursor(0, 0);
  lcd.print(F(" Smart Irrigation  "));
  lcd.setCursor(0, 1);
  lcd.print(F(" Firmware v2.0.0    "));
  lcd.setCursor(0, 2);
  lcd.print(F(" Booting System...  "));
}

// Mounts the on-flash filesystem holding the dashboard (data/index.html,
// manifest.json, sw.js). API routes still work even if this fails — the
// dashboard just won't be served from the board itself.
void initFilesystem() {
  filesystemOk = LittleFS.begin();
  if (filesystemOk) {
    Serial.println(F("[LittleFS] Mounted — dashboard will be served from the board."));
  } else {
    Serial.println(F("[LittleFS] Mount FAILED — upload the data/ folder with the LittleFS tool."));
  }
}

void initWiFi() {
  lcd.setCursor(0, 3);
  lcd.print(F(" WiFi: Connecting.. "));

  WiFi.mode(WIFI_STA);
  WiFi.begin(WIFI_SSID, WIFI_PASSWORD);

  uint32_t startAttempt = millis();
  while (WiFi.status() != WL_CONNECTED && (millis() - startAttempt < 8000)) {
    delay(250);
    Serial.print(F("."));
  }

  if (WiFi.status() == WL_CONNECTED) {
    Serial.print(F("\n[WiFi] Connected! IP Address: "));
    Serial.println(WiFi.localIP());
    Serial.print(F("[WiFi] Dashboard:  http://"));
    Serial.println(WiFi.localIP());
    Serial.println(F("[WiFi]        or: http://smart-irrigation.local"));
    lcd.setCursor(0, 3);
    lcd.print(F(" WiFi: Connected!   "));
  } else {
    Serial.println(F(
        "\n[WiFi] Connection timeout. Operating in Standalone/Offline mode."));
    lcd.setCursor(0, 3);
    lcd.print(F(" WiFi: Offline Mode "));
  }
  delay(1200);
  lcd.clear();
}

// =================================================================================
// 8. CORE SYSTEM TASKS
// =================================================================================
void taskServiceNetwork() {
  server.handleClient();
  MDNS.update();

  uint32_t now = millis();
  if (now - sysState.lastWiFiCheckTime >= 10000) {
    sysState.lastWiFiCheckTime = now;
    if (WiFi.status() != WL_CONNECTED) {
      WiFi.reconnect();
    }
  }
}

void taskReadSensors() {
  uint32_t now = millis();

  // Read Soil Moisture every 500ms using sample smoothing
  if (now - sysState.lastSensorReadTime >= 500) {
    sysState.lastSensorReadTime = now;

    sysState.rawSoilAnalog = analogRead(HardwarePin::SOIL_SENSOR);
    sysState.soilMoisture = readFilteredSoilMoisture();

    // Check sensor disconnection (Analog reading floating > 1010)
    sysState.soilSensorError =
        (sysState.rawSoilAnalog > 1010 && SoilCalibration::RAW_DRY < 950);

    // Read DHT sensor (the DHT library internally rate-limits actual
    // hardware polls to its minimum sample interval and returns the last
    // cached reading otherwise, so calling this every 500ms is safe)
    float t = dht.readTemperature();
    float h = dht.readHumidity();

    // Physical sanity validation: Catch NaN or out-of-range sensor readings
    // (e.g. DHT11/DHT22 type mismatch)
    if (isnan(t) || isnan(h) || t < -40.0f || t > 100.0f || h < 0.0f ||
        h > 100.0f) {
      sysState.dhtSensorError = true;
    } else {
      sysState.temperature = t;
      sysState.humidity = h;
      sysState.dhtSensorError = false;
    }
  }
}

int readFilteredSoilMoisture() {
  long sum = 0;
  for (uint8_t i = 0; i < SoilCalibration::FILTER_SAMPLES; i++) {
    sum += analogRead(HardwarePin::SOIL_SENSOR);
    delayMicroseconds(100);
  }
  int avgRaw = sum / SoilCalibration::FILTER_SAMPLES;

  int moisture =
      map(avgRaw, SoilCalibration::RAW_DRY, SoilCalibration::RAW_WET, 0, 100);
  return constrain(moisture, 0, 100);
}

void debounceButton(ButtonDebouncer &btn, void (*onPress)()) {
  bool reading = digitalRead(btn.pin);
  uint32_t now = millis();

  if (reading != btn.lastState) {
    btn.lastDebounceTime = now;
  }

  if ((now - btn.lastDebounceTime) > DEBOUNCE_DELAY_MS) {
    if (reading != btn.currentState) {
      btn.currentState = reading;
      if (btn.currentState == LOW) { // Active LOW button press
        onPress();
      }
    }
  }
  btn.lastState = reading;
}

void taskHandleButtons() {
  debounceButton(btnManual, []() {
    Serial.println(F("[Button] Manual Override Button Pressed"));
    setSystemMode(SystemMode::MANUAL, "Physical Button Trigger");
    PumpState targetState =
        (sysState.pump == PumpState::OFF) ? PumpState::ON : PumpState::OFF;
    executePumpState(targetState, "Physical Button Toggle", true);
  });

  debounceButton(btnAuto, []() {
    Serial.println(F("[Button] Auto Mode Button Pressed"));
    setSystemMode(SystemMode::AUTO, "Physical Button Trigger");
  });
}

void taskIrrigationControl() {
  uint32_t now = millis();

  // Safety Cutoff 1: Max continuous runtime limit
  if (sysState.pump == PumpState::ON) {
    if (now - sysState.pumpStartTime >= config.maxRuntimeMs) {
      executePumpState(PumpState::OFF, "Safety: Max Runtime Limit Reached",
                       true);
      return;
    }
  }

  // Safety Cutoff 2: Soil sensor failure
  if (sysState.soilSensorError && sysState.pump == PumpState::ON) {
    executePumpState(PumpState::OFF, "Safety: Soil Sensor Fault", true);
    return;
  }

  // Automatic Hysteresis Engine
  if (sysState.mode == SystemMode::AUTO) {
    if (sysState.soilMoisture < config.startThreshold &&
        sysState.pump == PumpState::OFF) {
      executePumpState(PumpState::ON, "Auto: Soil Moisture Below Threshold");
    } else if (sysState.soilMoisture >= config.stopThreshold &&
               sysState.pump == PumpState::ON) {
      executePumpState(PumpState::OFF, "Auto: Target Moisture Reached");
    }
  }
}

// =================================================================================
// 9. ACTUATOR CONTROL & STATE MUTATIONS
// =================================================================================
bool executePumpState(PumpState newState, const char *reason,
                      bool bypassLockout) {
  uint32_t now = millis();

  // Chatter protection for Automatic Mode triggers
  if (!bypassLockout &&
      (now - sysState.lastRelayToggleTime < MIN_AUTO_CHATTER_DELAY_MS)) {
    Serial.print(
        F("[Actuator] Chatter lockout active. Suppressing auto request: "));
    Serial.println(reason);
    return false;
  }

  if (newState == sysState.pump) {
    return true; // State unchanged
  }

  sysState.pump = newState;
  sysState.lastRelayToggleTime = now;
  sysState.lastLCDRefreshTime = 0; // Force immediate display update

  if (newState == PumpState::ON) {
    digitalWrite(HardwarePin::RELAY, RelayLogic::ACTIVE);
    sysState.pumpStartTime = now;
    Serial.print(F("[ACTUATOR] RELAY ON | Reason: "));
    Serial.println(reason);
  } else {
    digitalWrite(HardwarePin::RELAY, RelayLogic::INACTIVE);
    Serial.print(F("[ACTUATOR] RELAY OFF | Reason: "));
    Serial.println(reason);
  }
  return true;
}

void setSystemMode(SystemMode newMode, const char *reason) {
  if (sysState.mode != newMode) {
    sysState.mode = newMode;
    sysState.lastLCDRefreshTime = 0; // Force immediate display refresh
    Serial.print(F("[System] Mode changed to: "));
    Serial.print(newMode == SystemMode::AUTO ? "AUTO" : "MANUAL");
    Serial.print(F(" | Reason: "));
    Serial.println(reason);
  }
}

// =================================================================================
// 10. 20x4 LCD DIFFERENTIAL RENDERING ENGINE
// =================================================================================
void taskUpdateDisplay() {
  uint32_t now = millis();
  if (now - sysState.lastLCDRefreshTime < 1500) {
    return;
  }
  sysState.lastLCDRefreshTime = now;

  char buf[21];

  // ROW 0: Soil Moisture & Mode
  lcd.setCursor(0, 0);
  snprintf(buf, sizeof(buf), "Soil:%3d%% Mode:%-6s", sysState.soilMoisture,
           sysState.mode == SystemMode::AUTO ? "AUTO" : "MANUAL");
  lcd.print(buf);

  // ROW 1: Temperature & Pump Status
  lcd.setCursor(0, 1);
  if (sysState.dhtSensorError) {
    snprintf(buf, sizeof(buf), "Temp: ERR   Pump:%-3s",
             sysState.pump == PumpState::ON ? "ON" : "OFF");
  } else {
    snprintf(buf, sizeof(buf), "Temp: %2dC   Pump:%-3s",
             (int)sysState.temperature,
             sysState.pump == PumpState::ON ? "ON" : "OFF");
  }
  lcd.print(buf);

  // ROW 2: Humidity & Wi-Fi Connection
  lcd.setCursor(0, 2);
  if (sysState.dhtSensorError) {
    snprintf(buf, sizeof(buf), "Hum : ERR   WiFi:%-3s",
             WiFi.status() == WL_CONNECTED ? "ON" : "OFF");
  } else {
    snprintf(buf, sizeof(buf), "Hum : %2d%%   WiFi:%-3s",
             (int)sysState.humidity,
             WiFi.status() == WL_CONNECTED ? "ON" : "OFF");
  }
  lcd.print(buf);

  // ROW 3: Status Summary
  lcd.setCursor(0, 3);
  if (sysState.soilSensorError) {
    lcd.print(F("Status: SENSOR FAULT"));
  } else if (sysState.pump == PumpState::ON &&
             sysState.mode == SystemMode::AUTO) {
    lcd.print(F("Status: Auto Water  "));
  } else if (sysState.pump == PumpState::ON &&
             sysState.mode == SystemMode::MANUAL) {
    lcd.print(F("Status: Manual Water"));
  } else if (sysState.mode == SystemMode::MANUAL) {
    lcd.print(F("Status: Standby(MAN)"));
  } else {
    lcd.print(F("Status: Monitoring  "));
  }
}

// =================================================================================
// 11. REST API ENDPOINTS & CORS HEADERS
// =================================================================================
void sendCORSHeaders() {
  server.sendHeader(F("Access-Control-Allow-Origin"), F("*"));
  server.sendHeader(F("Access-Control-Allow-Methods"), F("GET, POST, OPTIONS"));
  server.sendHeader(F("Access-Control-Allow-Headers"), F("Content-Type"));
}
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

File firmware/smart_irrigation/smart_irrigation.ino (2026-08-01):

/*==============================================================================
  SMART IRRIGATION SYSTEM  —  ESP32 firmware
  --------------------------------------------------------------------------
  Hardware (from the project circuit diagram):
    ESP32 Dev Module, DHT11 (temp/hum), capacitive/resistive soil moisture,
    LDR light module, LCD 20x4 (I2C), 2-channel relay (water pump + spare),
    3 tactile buttons (MANUAL / MENU / SETTINGS), red + green status LEDs,
    3.7V Li-ion + SPDT power switch.

  Features:
    * AUTO watering with hysteresis (start below DRY%, stop above WET%)
    * MANUAL override (button toggles pump)
    * Optional "water only at night" using the LDR
    * Safety: max continuous pump run-time + cooldown between waterings
    * Sensor-fault handling (DHT NaN / soil sensor unplugged)
    * LCD dashboard + 3-button menu to change settings live
    * Settings saved to flash (survive power-off) via Preferences (NVS)

  Libraries (Library Manager):
    - "LiquidCrystal I2C" by Frank de Brabander
    - "DHT sensor library" by Adafruit  (+ "Adafruit Unified Sensor")
    Preferences + Wire ship with the ESP32 core.

  Board: "ESP32 Dev Module".   See README.md for wiring + calibration.
==============================================================================*/

#include <Wire.h>
#include <LiquidCrystal_I2C.h>
#include <DHT.h>
#include <Preferences.h>

/*------------------------------------------------------------------------------
  PIN MAP  —  VERIFY THESE AGAINST YOUR OWN WIRING (they are the only thing that
  must match your board). Change a number here if your diagram used another pin.
------------------------------------------------------------------------------*/
#define PIN_DHT          4    // DHT11  DATA
#define PIN_SOIL         34   // Soil moisture  A0  (ADC1, input-only)
#define PIN_LDR          35   // LDR module     OUT (ADC1, input-only)
#define PIN_SDA          18   // LCD 20x4  I2C SDA   (diagram: "D18 (SDA)")
#define PIN_SCL          19   // LCD 20x4  I2C SCL   (diagram: "D19 (SCL)")
#define PIN_RELAY_PUMP   22   // Relay IN1 -> water pump
#define PIN_RELAY_AUX    23   // Relay IN2 -> spare (2nd pump / solenoid valve)
#define PIN_BTN_MANUAL   25   // MANUAL ON/OFF button
#define PIN_BTN_MENU     26   // MENU button
#define PIN_BTN_SET      27   // SETTINGS button
#define PIN_LED_GREEN    17   // green LED  (system OK / soil moist)
#define PIN_LED_RED      16   // red LED    (pump running / dry / alert)

/*------------------------------------------------------------------------------
  HARDWARE OPTIONS
------------------------------------------------------------------------------*/
#define DHTTYPE          DHT11
#define LCD_ADDR         0x27      // if the screen stays blank, try 0x3F
#define RELAY_ACTIVE_LOW 1         // most blue 2-ch relay boards are active-LOW

#if RELAY_ACTIVE_LOW
  #define RLY_ON   LOW
  #define RLY_OFF  HIGH
#else
  #define RLY_ON   HIGH
  #define RLY_OFF  LOW
#endif

/*------------------------------------------------------------------------------
  CALIBRATION  (see README "Calibrating the soil sensor")
  ESP32 ADC is 12-bit: raw values run 0..4095.
------------------------------------------------------------------------------*/
int SOIL_RAW_DRY   = 3200;   // reading in dry air / bone-dry soil
int SOIL_RAW_WET   = 1300;   // reading in a glass of water
int LDR_RAW_DARK   = 200;    // reading in the dark
int LDR_RAW_BRIGHT = 3500;   // reading in bright light

/*------------------------------------------------------------------------------
  TIMING
------------------------------------------------------------------------------*/
const uint32_t DHT_PERIOD  = 2000;   // DHT11 max ~0.5 Hz
const uint32_t SOIL_PERIOD = 1000;
const uint32_t UI_PERIOD   = 300;
const uint32_t DEBOUNCE_MS = 40;

/*------------------------------------------------------------------------------
  OBJECTS / STATE
------------------------------------------------------------------------------*/
LiquidCrystal_I2C lcd(LCD_ADDR, 20, 4);
DHT dht(PIN_DHT, DHTTYPE);
Preferences prefs;

enum Mode  { MODE_AUTO = 0, MODE_MANUAL = 1 };
enum UI    { UI_HOME = 0, UI_MENU = 1, UI_EDIT = 2 };

struct Settings {
  uint8_t  mode         = MODE_AUTO;
  uint8_t  soilDry      = 35;   // %  start watering below this
  uint8_t  soilWet      = 55;   // %  stop watering above this
  uint16_t pumpMaxRun   = 30;   // s  safety cut-off for one watering
  uint16_t pumpCooldown = 60;   // s  minimum wait between waterings
  uint8_t  nightOnly    = 0;    // 1 = only water when it is dark
};
Settings cfg;

// live readings
float   tempC = NAN, humid = NAN;
int     soilRaw = 0, ldrRaw = 0;
int     soilPct = 0, lightPct = 0, lightLux = 0;
bool    soilOk = false, dhtOk = false;

// pump
bool     pumpOn = false, manualPump = false;
uint32_t pumpStartMs = 0, pumpStopMs = 0;

// ui
uint8_t  uiState = UI_HOME;
int8_t   menuIdx = 0;
const uint8_t MENU_COUNT = 7;   // Mode, Dry, Wet, MaxRun, Cooldown, Night, Save

// scheduler
uint32_t tDht = 0, tSoil = 0, tUi = 0;

/*==============================  BUTTONS  ====================================*/
struct Btn { uint8_t pin; bool last; uint32_t t; };
Btn bMan { PIN_BTN_MANUAL, HIGH, 0 };
Btn bMen { PIN_BTN_MENU,   HIGH, 0 };
Btn bSet { PIN_BTN_SET,    HIGH, 0 };

// returns true once on a fresh press (active-LOW, debounced)
bool pressed(Btn &b) {
  bool r = digitalRead(b.pin);
  if (r != b.last && (millis() - b.t) > DEBOUNCE_MS) {
    b.t = millis();
    b.last = r;
    if (r == LOW) return true;
  }
  return false;
}

/*==============================  SENSORS  ====================================*/
int clampi(int v, int lo, int hi) { return v < lo ? lo : (v > hi ? hi : v); }

void readSoil() {
  // average a few samples to steady the ADC
  long acc = 0;
  for (int i = 0; i < 8; i++) { acc += analogRead(PIN_SOIL); delay(2); }
  soilRaw = acc / 8;
  soilOk  = (soilRaw > 50 && soilRaw < 4090);        // unplugged -> stuck at rail
  int pct = map(soilRaw, SOIL_RAW_DRY, SOIL_RAW_WET, 0, 100);
  soilPct = clampi(pct, 0, 100);
}

void readLight() {
  long acc = 0;
  for (int i = 0; i < 8; i++) { acc += analogRead(PIN_LDR); delay(2); }
  ldrRaw   = acc / 8;
  int pct  = map(ldrRaw, LDR_RAW_DARK, LDR_RAW_BRIGHT, 0, 100);
  lightPct = clampi(pct, 0, 100);
  lightLux = lightPct * 10;   // rough relative estimate (0..1000), not calibrated lux
}

void readDht() {
  float t = dht.readTemperature();
  float h = dht.readHumidity();
  dhtOk = !(isnan(t) || isnan(h));
  if (dhtOk) { tempC = t; humid = h; }     // keep last good on a bad read
}

/*==============================  PUMP / CONTROL  =============================*/
void setPump(bool on) {
  if (on == pumpOn) return;
  pumpOn = on;
  digitalWrite(PIN_RELAY_PUMP, on ? RLY_ON : RLY_OFF);
  if (on) pumpStartMs = millis(); else pumpStopMs = millis();
  Serial.printf("[PUMP] %s\n", on ? "ON" : "OFF");
}
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

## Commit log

2026-08-01 Project 29 — Smart Irrigation System
    ESP32-based automatic plant-watering controller.
    - Firmware: sensor loop, LCD menu, relay control, NVS settings
    - Wi-Fi API: /api/state, /api/pump, /api/mode, /api/set (ESPAsyncWebServer)
    - Web dashboard: single-file HTML/CSS/JS, live + demo mode, mobile responsive
    - Wokwi simulation: diagram.json + sketch.ino
    - Enclosure: 3D-printed body + lid (150x120x60 mm), STEP + STL files
    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
    [body.stl, irrigation_body.stl, irrigation_body_cm.step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]
2026-08-11 Switch to ESP8266 firmware + installable PWA dashboard
    - New ESP8266 REST firmware (DHT22 + relay + mDNS): /api/status, /api/config,
    POST /api/pump, /api/mode, /api/config; safety-off bypasses chatter guard;
    config inputs clamped to safe ranges
    - Replace dashboard with a Vite PWA (offline service worker, install prompt,
    3s polling) wired to the REST API; keep the full-bleed video background
    - Regenerate firmware/software report + wiring diagram for ESP8266
    - Update README, .gitignore (node_modules/dist), Wokwi board note
    [build_software_report.py, draw_wiring.py, smart_irrigation_esp8266.ino]
2026-08-12 Restore original dashboard UI on the ESP8266 setup
    - Bring back the single-file dashboard (canvas gauge, sparklines, soil-trend
    chart, floating nav, gradient-mesh + video background, demo mode)
    - Wire it to the ESP8266 REST API: GET /api/status + /api/config, POST
    /api/pump {state}, /api/mode {mode}, /api/config
    - Drop light/cooldown/night (not on this board); ESP8266/DHT22 labels
    - Keep it installable: manifest link + offline service worker; trim sw.js
    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
2026-08-12 Add PWA install button to the dashboard
    - Shows only when the browser fires beforeinstallprompt (HTTPS/localhost)
    - Bump service-worker cache version so the new markup isn't served stale
2026-08-12 Serve the dashboard directly from the ESP8266 (LittleFS)
    - New firmware/smart_irrigation_esp8266/data/ holds a lightweight build of
    the dashboard (gradient-mesh background instead of video, which is ~4.7MB
    and won't fit on-board). Same UI/API as webapp/index.html otherwise.
    - Firmware mounts LittleFS and serves / /index.html /manifest.json /sw.js;
    falls back gracefully (API still works) if the filesystem isn't uploaded.
    - Verified: compiles clean against esp8266:esp8266 core 3.1.2, and the
    data/ folder round-trips byte-identical through the real mklittlefs tool
    at the default 2MB FS partition (files total ~60KB).
    - README: document both dashboard builds, the LittleFS upload step, a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
    [smart_irrigation_esp8266.ino]
2026-08-12 Fix metric-card grid to 3 columns (was still sized for 4)
    The Soil/Temperature/Humidity row was still using the 4-column grid from
    before the Light card was removed, leaving a phantom empty column on the
    right at every breakpoint. Now repeat(3,1fr) so the row fills correctly,
    plus tightened sizing so the mobile 3-across layout doesn't feel cramped.
2026-08-12 Upgrade firmware to v2.0.0 (LCD, buttons, EEPROM), keep old-UI dashboard
    - Adopt the provided v2.0.0 firmware: EEPROM-persisted config, 20x4 LCD
    status display, physical Manual/Auto buttons, moving-average soil filter,
    watchdog feed. REST API surface is unchanged (/api/status, /api/config,
    /api/pump, /api/mode) so the dashboard needed no changes.
    - Fixed before adopting: real Wi-Fi credentials in the source were replaced
    with placeholders (never commit real ones); DHTTYPE corrected to DHT22
    to match the wired sensor; POST /api/config now clamps thresholds to
    0-100 and runtime to 3s-10min again (the supplied file had dropped this);
    added MDNS.addService for full mDNS advertiseme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
    [smart_irrigation_esp8266.ino]
